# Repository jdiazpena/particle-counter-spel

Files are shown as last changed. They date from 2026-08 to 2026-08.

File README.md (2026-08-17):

# SUCHAI Particle Counter

This repository collects the hardware designs, Raspberry Pi Pico firmware, and
Raspberry Pi acquisition/postprocessing software used to build and operate a
prototype particle counter.

> **Project status:** prototype and research use. The repository is not yet a
> build-ready release. The plotting pipeline has a known altitude-column
> mismatch, and reproducible build/test environments have not yet been
> recorded. Review [Known issues](docs/known-issues.md) before manufacturing
> hardware or processing measurements.

## System overview

```text
S1223-01 photodiode
    -> analog front end
    -> four thresholds per detector (A and B)
    -> Raspberry Pi Pico pulse counters
    -> I2C
    -> Raspberry Pi Zero 2 acquisition
    -> CSV measurements
    -> TLE orbit propagation
    -> geographic and magnetic plots
```

The comparator board produces eight digital channels. `A1` through `A4` are
the four cumulative threshold outputs for detector A; `B1` through `B4` are
the corresponding outputs for detector B. The Pico counts their rising edges
and exposes eight cumulative 32-bit counters to the Raspberry Pi over I2C.

## Repository layout

```text
hardware/
  analog-front-end/             Photodiode amplifier/interstage KiCad project
  comparator-pico-interface/    Comparator, DAC, power, and Pico KiCad project
firmware/
  pico-particle-counter/        RP2040/Arduino pulse-counter firmware
software/
  raspberry-pi/                 Acquisition, orbit processing, and plotting
docs/
  hardware.md                   Boards, connectors, and signal mapping
  firmware.md                   Pico behavior, pin mapping, and I2C protocol
  raspberry-pi-software.md      Acquisition and postprocessing programs
  data-format.md                Measurement columns and derived products
  known-issues.md               Software, reproducibility, and portability limits
```

## Documentation

- [Hardware and wiring](docs/hardware.md)
- [Pico firmware](docs/firmware.md)
- [Raspberry Pi software](docs/raspberry-pi-software.md)
- [Data format](docs/data-format.md)
- [Known issues](docs/known-issues.md)

## Typical workflow

1. Review the schematics, run KiCad ERC/DRC, and assemble and verify the analog
   front end and comparator/interface boards.
2. Flash the Pico with
   [`pico_particle_counter.ino`](firmware/pico-particle-counter/pico_particle_counter.ino).
3. Connect the Pico and MCP4728 to the Raspberry Pi I2C bus.
4. Set the desired threshold voltages in
   [`MCPleves.txt`](software/raspberry-pi/MCPleves.txt).
5. Record detector A, detector B, or both using the corresponding acquisition
   script in [`software/raspberry-pi`](software/raspberry-pi).
6. Add suitable TLE files and run the orbit-cache postprocessor.
7. After addressing the documented `alt_km`/`alt` issue, generate geographic
   and magnetic-coordinate plots.

Detailed commands, paths, dependencies, and output descriptions are in the
linked documents. There is currently no published voltage-to-particle-energy
calibration, so threshold-difference products must not be described as
calibrated energy bins.

## Contributing changes

Keep hardware, firmware, and software revisions traceable. When changing a
board, record whether the schematic or PCB was the starting authority, update
both, run KiCad ERC/DRC, and document the tested physical revision. Avoid
committing KiCad lock/session/cache files or Python bytecode.

## License

No license has been added yet. Until the project owners select one, the files
should not be assumed to grant permission for redistribution or reuse.

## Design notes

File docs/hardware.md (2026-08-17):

# Hardware

The hardware is divided into an analog photodiode front end and a combined
comparator, threshold-DAC, power-control, and Pico interface board. Both are
KiCad 9 projects.

## Analog front end

Project directory: [`hardware/analog-front-end`](../hardware/analog-front-end)

The current design contains:

- one Hamamatsu S1223-01 photodiode (`D1`);
- a dual operational-amplifier stage (`IC1`);
- a REF3012 voltage reference (`U1`);
- transimpedance/filter/gain components;
- internal signals `OUTA` and `OUTB` and the connector output `OUT`;
- 5 V power and ground connections; and
- a routed two-layer, 1.6 mm PCB with 32 footprints.

The schematic is the authoritative source for component selection. The current
schematic and PCB have matching component references and displayed values. The
connector mapping below is extracted from the current
`PC_Interstage.kicad_pcb` file.

| Connector | Pin 1 | Pin 2 | Pin 3 | Pin 4 |
|---|---|---|---|---|
| J1, J7, J8, J9 | GND | 5V0 | OUT | GND |
| J6 | GND | 5V0 | OUT | GND |
| J2, J3, J4, J5 | GND | — | — | — |

Matching values do not by themselves establish electrical correctness or prove
that the PCB has been updated from the latest schematic netlist. Run ERC, update
the PCB from the schematic, and run DRC before manufacturing.

## Comparator and Pico interface

Project directory:
[`hardware/comparator-pico-interface`](../hardware/comparator-pico-interface)

The board contains:

- two LM339 quad comparators (`U5`, `U6`);
- one MCP4728 four-channel threshold DAC (`U7`);
- one Raspberry Pi Pico module (`A1`);
- separate particle-detector and camera power switching;
- AP2112K 3.3 V regulators and TPS22917 load switches;
- two analog inputs, `PC_AO1` and `PC_AO2`;
- comparator outputs `A1`–`A4` and `B1`–`B4`; and
- a routed four-layer, 1.6 mm PCB.

The current schematic and PCB have matching component references and values.
This does not constitute ERC, DRC, or physical validation.

### Functional connections

| Function | Current PCB connection |
|---|---|
| Analog input A | J2 pin 2, `PC_AO1` |
| Analog input B | J3 pin 2, `PC_AO2` |
| Comparator A outputs | J12 pins 4, 3, 2, 1 = A1, A2, A3, A4 |
| Comparator B outputs | J13 pins 4, 3, 2, 1 = B1, B2, B3, B4 |
| DAC thresholds | J9 pins 2–5 = REFA, REFB, REFC, REFD |
| Raspberry Pi I2C | `RPI_SDA`, `RPI_SCL` |
| Pico supply | `5V_PC` to Pico VSYS |

### Main 12-pin interface connector

The current `J1` PCB mapping is:

| Pin | Signal | Pin | Signal |
|---:|---|---:|---|
| 1 | GND | 7 | CAM_Switch |
| 2 | AGND | 8 | 3V3 |
| 3 | AGND | 9 | RPI_SDA |
| 4 | 5V0_IN | 10 | RPI_SCL |
| 5 | 5V0_IN | 11 | 5V0_IN |
| 6 | PD_Switch | 12 | GND |

Confirm connector orientation and pin-one markings in KiCad before wiring.

## KiCad file roles

Each project contains:

| Extension/name | Purpose | Version-control guidance |
|---|---|---|
| `.kicad_sch` | Editable electrical schematic | Track |
| `.kicad_pcb` | Board layout, footprints, routing, and outline | Track |
| `.kicad_pro` | Project and design-rule settings | Track |
| `.kicad_prl` | User-local editor/session state | Do not add new copies |
| `fp-info-cache` | Generated footprint-library cache | Do not add new copies |
| `*-backups/` | KiCad automatic working backups | Prefer tagged releases instead |
| `*.lck` | Temporary editor lock | Never track |

## External libraries and models

The designs use custom `SamacSys_Parts` and `Payload` libraries. Footprint
geometry already placed on a PCB is embedded in the board file, but editing or
re-associating some parts may require the original libraries. Several 3D model
references use absolute Windows paths under `D:\JMDP\...`; these models will
not render on another machine until the paths or libraries are configured.

Before calling a revision reproducible, collect the custom symbols,
footprints, and redistributable 3D models into project-local libraries and
record the exact KiCad version used.

## Manufacturing checklist

Before ordering boards:

1. Record the authoritative schematic and hardware revision.
2. Update the PCB from the schematic and review all resulting changes.
3. Confirm op-amp stability, photodiode polarity, feedback values, and supply
   range from component datasheets.
4. Verify every connector pinout and mating-part orientation.
5. Run KiCad ERC and DRC with KiCad 9.
6. Generate and inspect Gerbers, drill files, position files, and the BOM.
7. Record a hardware revision identifier on both the PCB and documentation.
8. Bench-test power rails and threshold voltages before installing detectors.

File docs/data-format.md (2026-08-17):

# Measurement and processed data

## Raw measurement CSV

The acquisition scripts write one row per integration window.

### Common columns

| Column | Meaning | Unit/format |
|---|---|---|
| `unix_time` | Host time when the snapshot was read | Unix seconds, UTC |
| `iso_utc` | Human-readable host timestamp | ISO 8601 UTC |
| `t_s` | Elapsed monotonic time since acquisition start | seconds |

### Counter columns

Channel names encode detector, threshold number, and configured voltage. For
example, `A1_0.450V` is detector A at threshold 1 with a 0.450 V DAC setting.

An AB file contains eight count columns in this order:

```text
A1, A2, A3, A4, B1, B2, B3, B4
```

Values are counts observed during the integration window, not the Pico's raw
cumulative totals. The acquisition program computes:

```text
window_count = (new_total - previous_total) modulo 2^32
```

Threshold channels are cumulative discriminator products. A particle counted
above threshold 4 is normally also counted by thresholds 1, 2, and 3. Adding
all thresholds would therefore count the same event multiple times.

## Normalized count products

The orbit-cache postprocessor creates consistent columns even when an input
file contains only detector A or only detector B.

| Column | Definition |
|---|---|
| `count_A_thrN` | Detector A count at threshold N; zero if absent |
| `count_B_thrN` | Detector B count at threshold N; zero if absent |
| `thrN_total` | `count_A_thrN + count_B_thrN` |
| `particles_total` | `thr1_total` |
| `counts_total` | Backward-compatible alias of `particles_total` |
| `counts_A_total` | `count_A_thr1` |
| `counts_B_total` | `count_B_thr1` |
| `counts_raw_threshold_sum` | Sum of all four threshold totals; diagnostic only |
| `thresholdN_v` | Voltage parsed from the raw channel name |

`counts_raw_threshold_sum` must not be interpreted as a number of independent
particles.

## Approximate differential bins

The postprocessor derives:

```text
bin1 = max(thr1_total - thr2_total, 0)
bin2 = max(thr2_total - thr3_total, 0)
bin3 = max(thr3_total - thr4_total, 0)
bin4 = max(thr4_total, 0)
```

These are threshold intervals. They are not calibrated particle-energy bands
unless a detector-response and voltage-to-energy calibration is supplied.

## Provenance columns

| Column | Meaning |
|---|---|
| `detector_mode` | `A`, `B`, `AB`, or `UNKNOWN` |
| `source_file` | Original acquisition CSV path |
| `unix_time_key` | Unix timestamp normalized to six decimal places for joining |

The original raw channel columns are retained for debugging.

## Orbit columns

| Column | Meaning | Unit |
|---|---|---|
| `lat` | Geodetic latitude | degrees |
| `lon` | Geodetic longitude | degrees |
| `alt_km` | Geodetic altitude | kilometres |
| `jd` | Observation time | Julian date |
| `tle_epoch` | Epoch text from the selected TLE | TLE format |
| `tle_epoch_jd` | Selected TLE epoch | Julian date |
| `tle_file` | Source catalog path | text |
| `tle_hash` | SHA-1 identifier of the selected TLE pair | hexadecimal |
| `sgp4_error` | SGP4 status code | integer |
| `sgp4_error_text` | Description when propagation fails | text |

The plot helper currently expects `alt` rather than `alt_km`; this is a known
pipeline incompatibility, not a second documented altitude field.

## Plot-ready magnetic columns

The plotting helper is intended to add:

| Column | Meaning |
|---|---|
| `times` | Parsed UTC timestamp |
| `mlat` | AACGM magnetic latitude |
| `mlon` | AACGM magnetic longitude |
| `mlt` | Magnetic local time |
| `foot_lat`, `foot_lon` | Geographic coordinates of the magnetic footpoint |
| `period` | `1` for 06:00–18:00 MLT, `0` otherwise |

AACGM conversion can be undefined for some positions, especially near the
magnetic equator. Those rows are retained with missing magnetic coordinates.

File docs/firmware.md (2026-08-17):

# Raspberry Pi Pico firmware

Firmware directory:
[`firmware/pico-particle-counter`](../firmware/pico-particle-counter)

The Arduino sketch uses the RP2040 PIO blocks to count pulses on eight inputs.
Four state machines on PIO0 count detector A, and four on PIO1 count detector
B. Interrupt handlers increment one 32-bit software counter per channel.

## Pin mapping

| Counter index | Channel | Pico GPIO | PIO/state machine |
|---:|---|---:|---|
| 0 | A1 | GP22 | PIO0 SM0 |
| 1 | A2 | GP21 | PIO0 SM1 |
| 2 | A3 | GP20 | PIO0 SM2 |
| 3 | A4 | GP19 | PIO0 SM3 |
| 4 | B1 | GP6 | PIO1 SM0 |
| 5 | B2 | GP8 | PIO1 SM1 |
| 6 | B3 | GP10 | PIO1 SM2 |
| 7 | B4 | GP12 | PIO1 SM3 |
| — | I2C SDA | GP4 | `Wire` slave interface |
| — | I2C SCL | GP5 | `Wire` slave interface |

The firmware disables internal pulls on all pulse inputs. The external circuit
must therefore provide valid logic levels and must not leave inputs floating.

## Counted event

Each PIO state machine performs this sequence:

```text
wait until input is low
wait until input is high
raise an interrupt and wait until it is cleared
repeat
```

One low-to-high transition is counted. A signal must return low before a later
pulse can be counted.

## I2C protocol

The Pico acts as an I2C slave:

| Property | Value |
|---|---|
| Address | `0x17` |
| SDA | GP4 |
| SCL | GP5 |
| Read length | 32 bytes |
| Payload | eight little-endian unsigned 32-bit totals |
| Channel order | A1, A2, A3, A4, B1, B2, B3, B4 |

The Raspberry Pi acquisition programs subtract successive snapshots using
modulo-2^32 arithmetic, so a single counter rollover is handled correctly.
The protocol has no command byte, version field, checksum, reset command, or
timestamp; the host timestamps each received snapshot.

## Source files

- [`pico_particle_counter.ino`](../firmware/pico-particle-counter/pico_particle_counter.ino)
  is the active Arduino sketch. It embeds the three PIO instructions directly.
- [`pulse_counter.pio`](../firmware/pico-particle-counter/pulse_counter.pio)
  is the readable PIO source representation.
- [`data/pulse_counter.pio`](../firmware/pico-particle-counter/data/pulse_counter.pio)
  is currently an identical duplicate. The sketch does not import either PIO
  file.

## Building and flashing

The repository does not yet pin an Arduino RP2040 core or toolchain version.
Until a tested version is recorded, use an Arduino environment that provides:

- `Arduino.h` and `Wire.h` for an RP2040/Pico target; and
- the Raspberry Pi Pico SDK hardware headers used by the sketch, including
  PIO, IRQ, GPIO, synchronization, and PIO instruction helpers.

Select the exact Raspberry Pi Pico target, compile the sketch, upload it over
USB, and confirm that the built-in LED produces a short flash approximately
once per second. Then verify I2C address `0x17` from the Raspberry Pi before
connecting live comparator outputs.

Record the tested board package, version, compiler, upload command, and Pico
model here when a reproducible firmware build is established.

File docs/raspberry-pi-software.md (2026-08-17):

# Raspberry Pi software

Software directory: [`software/raspberry-pi`](../software/raspberry-pi)

The software has three stages: acquire counter snapshots, attach orbital
position to each timestamp, and produce geographic/magnetic plots.

## Platform assumptions

The acquisition programs assume:

- a Raspberry Pi with I2C bus 1 enabled;
- Pico I2C slave address `0x17`;
- MCP4728 DAC address `0x60` on the same bus;
- permission to access `/dev/i2c-1`; and
- writable `~/Documents/PD` and `~/Documents/PD_post` directories.

The code imports the following non-standard Python packages:

| Purpose | Packages/modules |
|---|---|
| I2C acquisition | `smbus2`, Adafruit Blinka (`board`), `adafruit_mcp4728` |
| Tables/numerics | `numpy`, `pandas` |
| Orbit propagation | `sgp4`, `astropy` |
| Mapping | `matplotlib`, `geopandas`, `shapely`, `cartopy`, `aacgmv2` |

No supported OS image, Python version, or dependency lock file is currently
provided. Install these in a virtual environment appropriate to the selected
Raspberry Pi OS, then record the tested versions before deployment.

## Threshold configuration

[`MCPleves.txt`](../software/raspberry-pi/MCPleves.txt) contains exactly four
threshold voltages, one per line. The current values are:

```text
0.45
1.0
1.55
2.1
```

The A and B acquisition scripts use this file and apply the same four DAC
thresholds to both detectors. Values must remain between 0 and 4.096 V.

`read_particle_counter.py` is an older diagnostic exception: it uses hardcoded
0.5, 1.5, 2.5, and 3.5 V thresholds instead of the file.

## Acquisition programs

Run commands from `software/raspberry-pi` so local configuration and helper
imports are easy to find.

### Both detectors

```bash
python3 read_pd_AB.py TOTAL_TIME_S INTEGRATION_TIME_S
```

For example, the following requests ten minutes of data in one-second
integration windows:

```bash
python3 read_pd_AB.py 600 1
```

It writes all eight channel deltas to a uniquely named
`~/Documents/PD/PD_AB_*.csv` file. Each row is flushed and synchronized to
storage.

### Detector A only

```bash
python3 read_pd_A.py TOTAL_TIME_S INTEGRATION_TIME_S
```

This saves only A1–A4 as `PD_A_only_*.csv`.

### Detector B only

```bash
python3 read_pd_B.py TOTAL_TIME_S INTEGRATION_TIME_S
```

This saves only B1–B4 as `PD_B_only_*.csv`.

### Live diagnostic

```bash
python3 read_particle_counter.py
```

This continuously prints cumulative totals and one-second deltas. It does not
write CSV data and uses its own hardcoded DAC thresholds. Stop it with
`Ctrl+C`.

## Orbit-position processing

[`pd_build_orbit_cache.py`](../software/raspberry-pi/pd_build_orbit_cache.py)
uses hardcoded directories:

| Path | Purpose |
|---|---|
| `~/Documents/PD` | Input `PD*.csv` measurement files |
| `~/TLE` | Input two-line element catalog files |
| `~/TLE/finals2000A.all` | Optional offline Earth-orientation data |
| `~/Documents/PD_post` | Cache, joined output, and runtime report |

Run:

```bash
python3 pd_build_orbit_cache.py
```

The program accepts TLE files containing either two-line pairs or a satellite
name followed by a two-line pair. For each measurement timestamp it selects
the nearest TLE epoch, propagates with SGP4, transforms TEME coordinates to an
Earth-fixed position, and stores latitude, longitude, and altitude.

The cache avoids repeating propagation unless a timestamp is new, its position
is missing, or an updated TLE catalog changes the nearest TLE.

Expected outputs are:

- `pd_orbit_cache.csv`;
- `pd_measurements_with_position.csv`; and
- `pd_orbit_cache_runtime.txt`.

## Plotting

[`plot_pd_particles.py`](../software/raspberry-pi/plot_pd_particles.py) expects
`~/Documents/PD_post/pd_measurements_with_position.csv`, builds an AACGM
magnetic-coordinate cache, and writes PNG figures under
`~/Documents/PD_post/figures_PD`.

Intended command:

```bash
python3 plot_pd_particles.py
```

The current producer writes `alt_km`, while the plotting helper expects `alt`.
Consequently this step is known to fail without a separately authorized code
fix or a manually adapted input table. See [Known issues](known-issues.md).

The plots include geographic coordinates, AACGM magnetic coordinates,
magnetic footpoints, day/night magnetic-local-time subsets, cumulative
threshold products, and approximate threshold-difference bins.

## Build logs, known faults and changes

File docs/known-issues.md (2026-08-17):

# Known issues and release blockers

This document records problems observed in the current repository. It does not
claim that the electrical design or scientific method has been fully reviewed.

## Plotting altitude mismatch

`pd_build_orbit_cache.py` produces `alt_km`, but `Help_Functions_PD.py`
requires `alt` and attempts to access `row.alt`. The intended joined output
therefore does not satisfy the plotting helper's schema.

This requires a code decision: either standardize on `alt_km` throughout or
rename it to `alt` while clearly preserving kilometre units. Code changes are
outside the documentation/reorganization change represented here.

## Missing reproducible environments

- No Python dependency or lock file is present.
- No supported Raspberry Pi OS/Python versions are recorded.
- No Arduino RP2040 core/toolchain version is recorded.
- No automated tests or hardware-in-the-loop checks are present.
- No CI workflow validates Python syntax or documentation links.

## KiCad portability

- Custom `SamacSys_Parts` and `Payload` libraries are not included as
  project-local libraries.
- Several 3D models refer to absolute Windows paths.
- The repository already contains tracked `.kicad_prl`, `fp-info-cache`, lock,
  and automatic-backup files. These are local/generated artifacts and may
  create noisy changes or disclose workstation-specific state.
- KiCad ERC and DRC reports are not included.

## Naming and stale references

- `MCPleves.txt` likely means `MCP_levels.txt`. It cannot be renamed without
  changing three acquisition scripts that reference it.
- Comments mention `pd_build_orbit_cache_v2.py`, which is not in the repository.
- The A-only and B-only usage messages mention filenames ending in `_only.py`,
  but the committed scripts are `read_pd_A.py` and `read_pd_B.py`.
- Two identical `pulse_counter.pio` files exist, and the Arduino sketch embeds
  its PIO instructions rather than importing either one.

## Threshold inconsistency

The primary acquisition scripts load 0.45, 1.0, 1.55, and 2.1 V from
`MCPleves.txt`. The live diagnostic `read_particle_counter.py` instead programs
0.5, 1.5, 2.5, and 3.5 V. Measurements must record which program and thresholds
were used.

## Missing project information

The repository still needs:

- an approved hardware revision and validation status;
- a BOM with manufacturer part numbers and substitutions;
- assembly photographs and connector-orientation diagrams;
- a detector calibration procedure and calibration data;
- representative raw and processed example data;
- expected plots for a known dataset;
- operating limits and electrical safety notes;
- contributor/citation information; and
- an explicit software/hardware/documentation license.

## Recommended release gate

Before labeling a version build-ready:

1. update each PCB from its authoritative schematic;
2. run and archive ERC/DRC results;
3. build and bench-test both boards;
4. pin and test the Pico and Raspberry Pi environments;
5. resolve the altitude schema mismatch;
6. run a complete acquisition-to-plot test with sample data;
7. add BOM, calibration, and expected results; and
8. tag the exact tested hardware, firmware, and software revision together.

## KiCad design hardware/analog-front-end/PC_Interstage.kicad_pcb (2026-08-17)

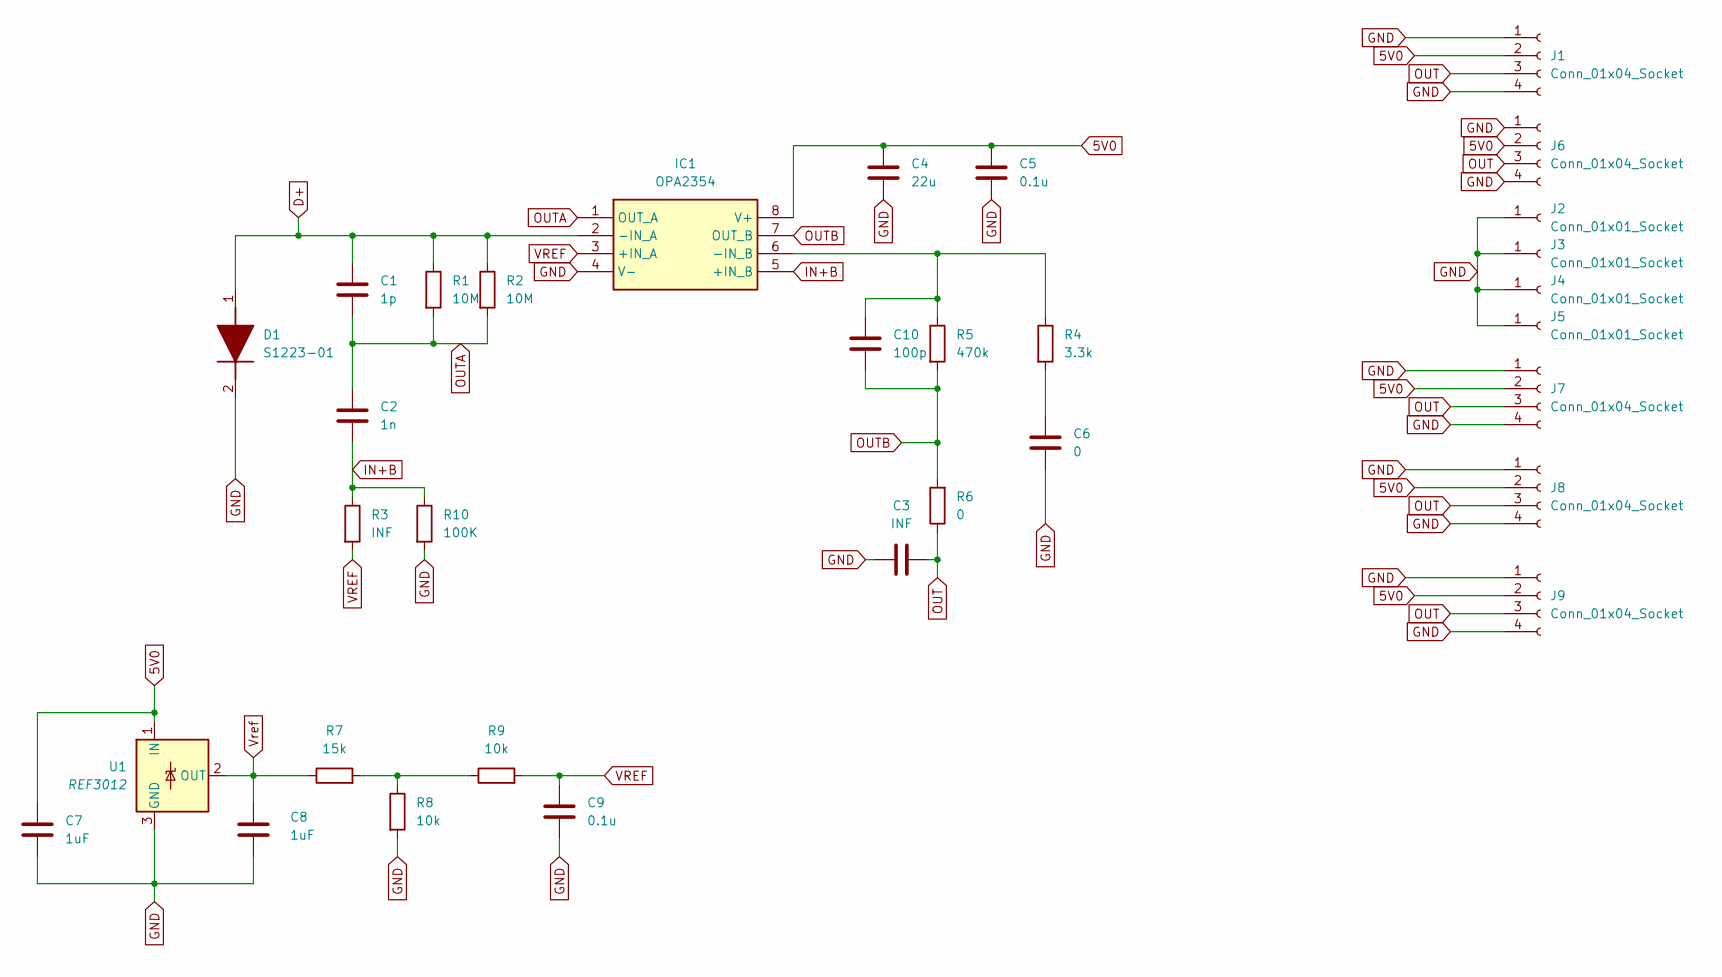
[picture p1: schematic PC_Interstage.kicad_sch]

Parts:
C1: 1p; C_0805_2012Metric
C2: 1n; C_0805_2012Metric
C3: INF; C_0805_2012Metric
C4: 22u; C_0805_2012Metric
C5, C9: 0.1u; C_0805_2012Metric
C6: 0; C_0805_2012Metric
C7, C8: 1uF; C_0805_2012Metric
C10: 100p; C_0805_2012Metric
D1: S1223-01; Manufacturer_Part_Number S1223-01
IC1: OPA2354; SOIC127P600X175-8N; Manufacturer_Part_Number OPA1678IDR; Mouser Part Number 595-OPA1678IDR
J1, J7, J8, J9: Conn_01x04_Socket; Molex_Pico-Lock_504050-0491_1x04-1MP_P1.50mm_Horizontal
J2, J3, J4, J5: Conn_01x01_Socket; PinHeader_1x01_P2.54mm_Vertical
J6: Conn_01x04_Socket; PinHeader_1x04_P2.54mm_Vertical
R1: 10M; R_0805_2012Metric
R2: 10M; R_1206_3216Metric_Pad1.30x1.75mm_HandSolder
R3: INF; R_0805_2012Metric
R4: 3.3k; R_0805_2012Metric
R5: 470k; R_0805_2012Metric
R6: 0; R_0805_2012Metric
R7: 15k; R_0805_2012Metric
R8, R9: 10k; R_0805_2012Metric
R10: 100K; R_0805_2012Metric
U1: REF3012; SOT-23

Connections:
5V0: C4.1, C5.1, C7.1, IC1.8 (V+), J1.2, J6.2, J7.2, J8.2, J9.2, U1.1 (IN)
D+: C1.1, D1.1 (A), IC1.2 (-IN_A), R1.1, R2.1
GND: C3.2, C4.2, C5.2, C6.2, C7.2, C8.2, C9.2, D1.2 (K), IC1.4 (V-), J1.1, J1.4, J2.1, J3.1, J4.1, J5.1, J6.1, J6.4, J7.1, J7.4, J8.1, J8.4, J9.1, J9.4, R8.2, R10.2, U1.3 (GND)
IN+B: C2.2, IC1.5 (+IN_B), R3.1, R10.1
unnamed: C6.1, R4.2
unnamed: C10.1, IC1.6 (-IN_B), R4.1, R5.1
unnamed: R7.2, R8.1, R9.1
OUT: C3.1, J1.3, J6.3, J7.3, J8.3, J9.3, R6.1
OUTA: C1.2, C2.1, IC1.1 (OUT_A), R1.2, R2.2
OUTB: C10.2, IC1.7 (OUT_B), R5.2, R6.2
VREF: C9.1, IC1.3 (+IN_A), R3.2, R9.2
Vref: C8.1, R7.1, U1.2 (OUT)

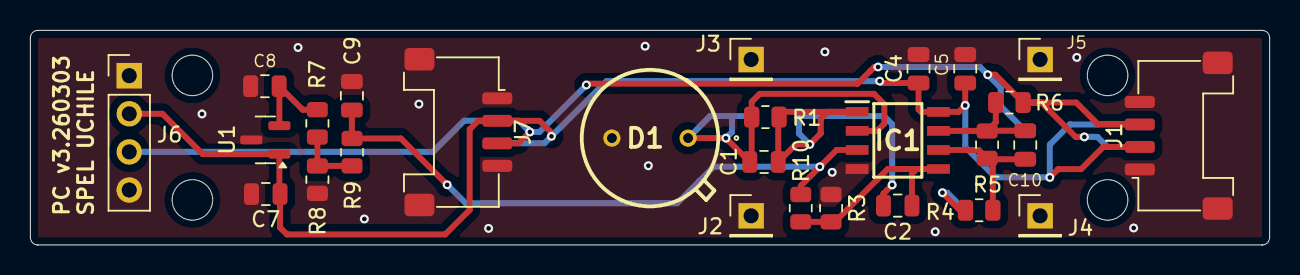
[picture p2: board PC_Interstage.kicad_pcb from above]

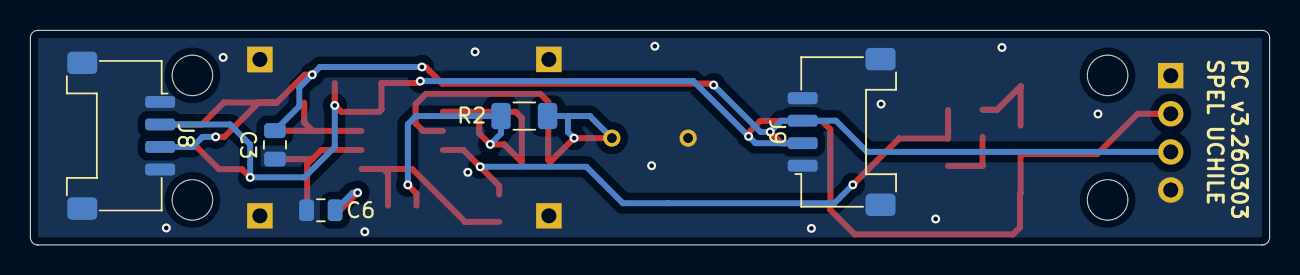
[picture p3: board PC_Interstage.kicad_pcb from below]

Board: 2 copper layers, 82.6 x 14.3 mm, 32 parts (5 on the bottom side), 12 nets.

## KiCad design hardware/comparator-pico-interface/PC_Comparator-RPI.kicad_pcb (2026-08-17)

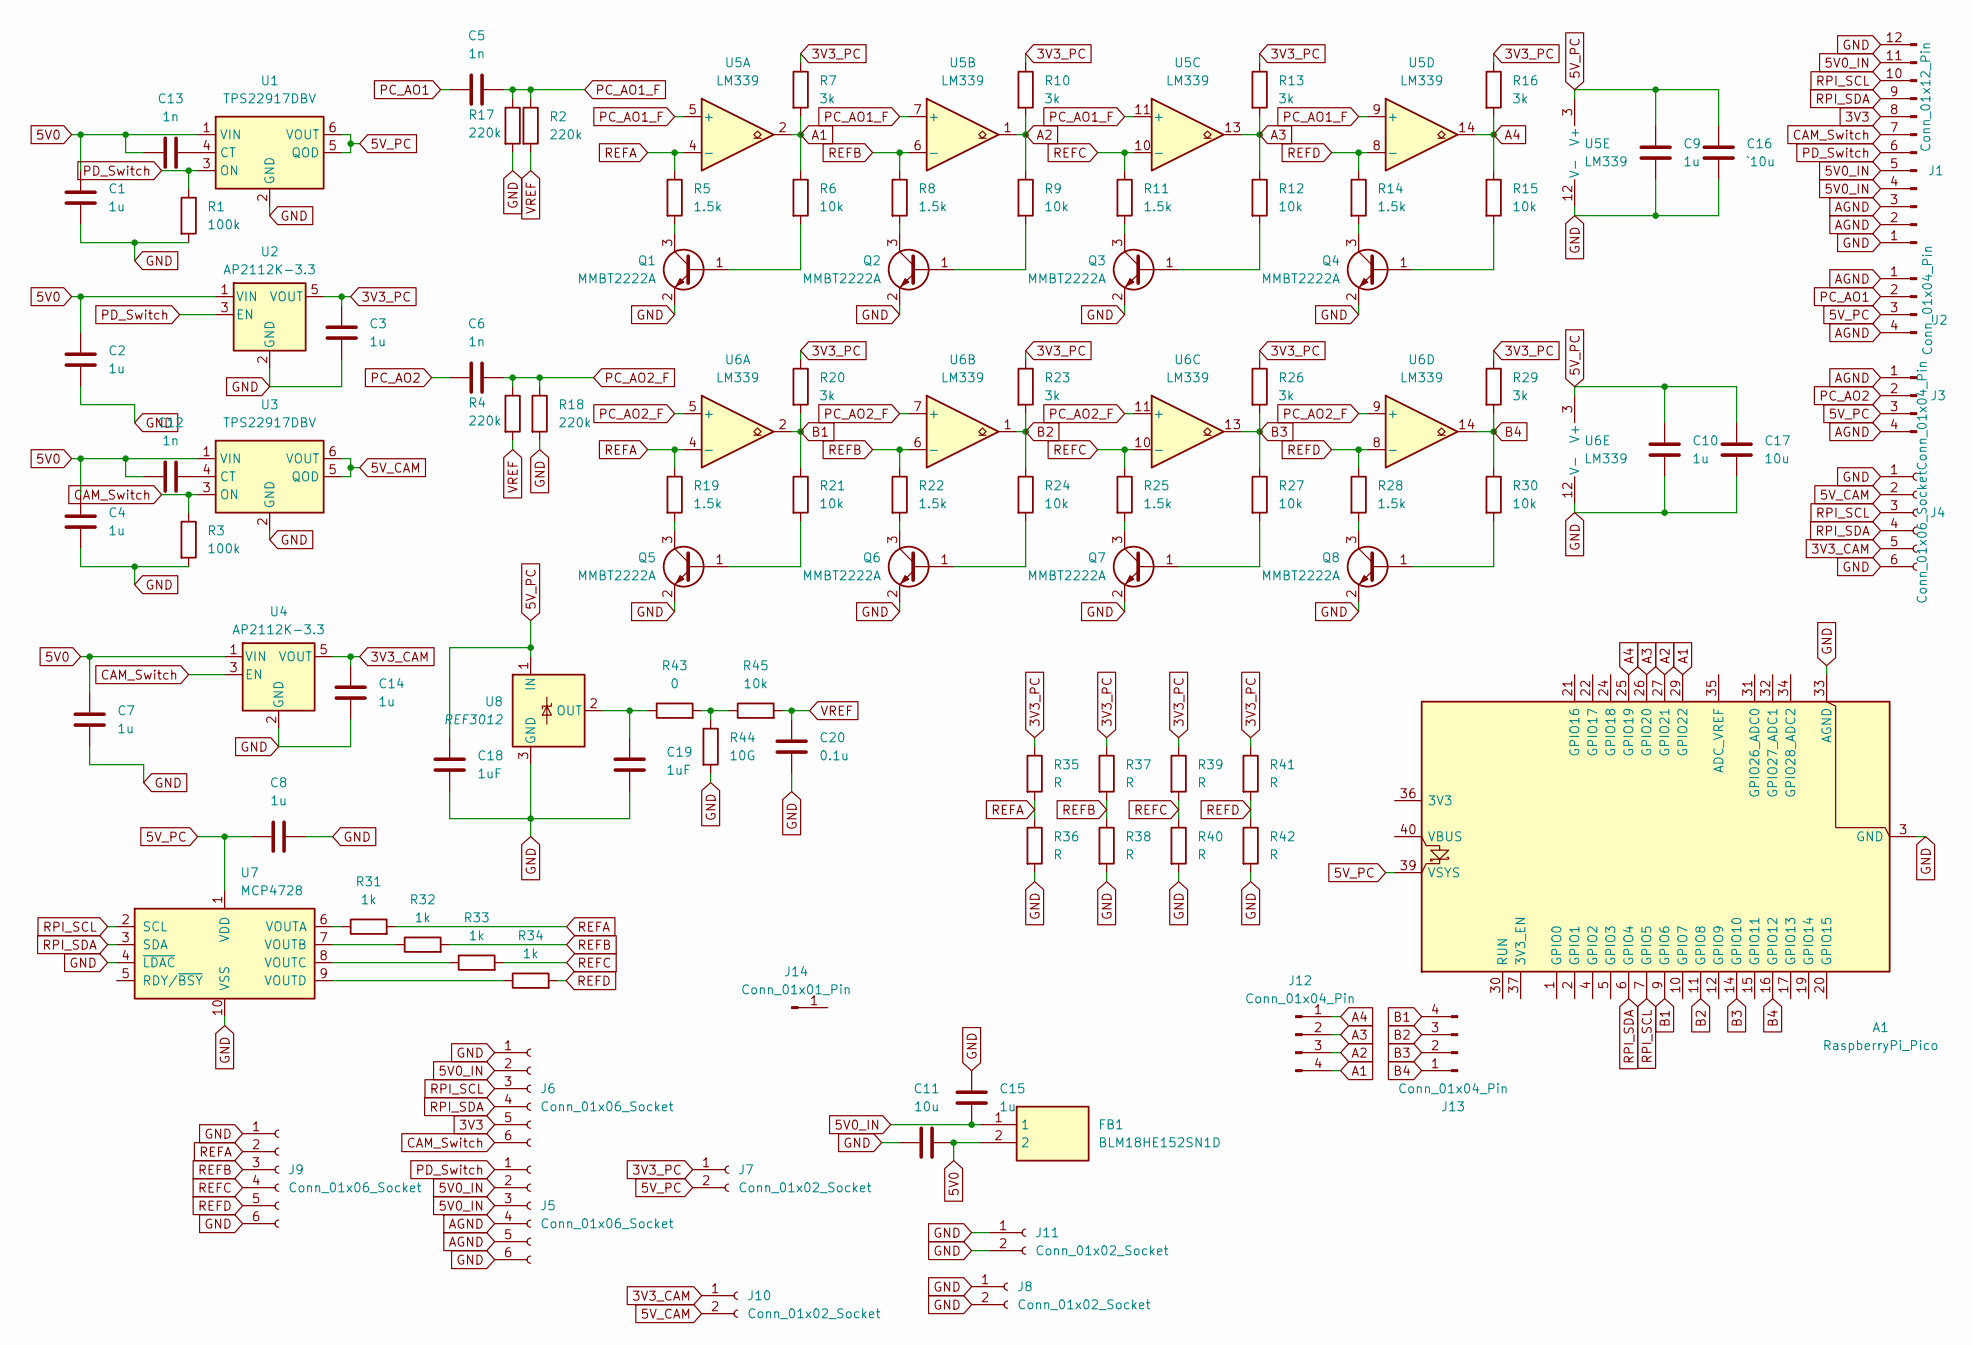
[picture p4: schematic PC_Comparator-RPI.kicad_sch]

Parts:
A1: RaspberryPi_Pico; RaspberryPi_Pico_Common_Unspecified
C1, C2, C3, C4, C7, C8, C9, C10, C14, C15: 1u; C_0805_2012Metric_Pad1.18x1.45mm_HandSolder
C5, C6, C12, C13: 1n; C_0805_2012Metric_Pad1.18x1.45mm_HandSolder
C11, C17: 10u; C_0805_2012Metric_Pad1.18x1.45mm_HandSolder
C16: `10u; C_0805_2012Metric_Pad1.18x1.45mm_HandSolder
C18, C19: 1uF; C_0805_2012Metric
C20: 0.1u; C_0805_2012Metric
FB1: BLM18HE152SN1D; BLM18SP221SN1B; Manufacturer_Part_Number BLM18HE152SN1D; Mouser Part Number 81-BLM18HE152SN1D
J1: Conn_01x12_Pin; 5040501291
J2, J3: Conn_01x04_Pin; Molex_Pico-Lock_504050-0491_1x04-1MP_P1.50mm_Horizontal
J4: Conn_01x06_Socket; Molex_Pico-Lock_504050-0691_1x06-1MP_P1.50mm_Horizontal
J5, J6, J9: Conn_01x06_Socket; PinSocket_1x06_P2.54mm_Vertical
J7, J8, J10, J11: Conn_01x02_Socket; PinHeader_1x02_P2.54mm_Vertical
J12, J13: Conn_01x04_Pin; PinHeader_1x04_P2.54mm_Vertical
J14: Conn_01x01_Pin; PinSocket_1x01_P2.54mm_Vertical
Q1, Q2, Q3, Q4, Q5, Q6, Q7, Q8: MMBT2222A; SOT-23
R1, R3: 100k; R_0805_2012Metric_Pad1.20x1.40mm_HandSolder
R2, R4, R17, R18: 220k; R_0805_2012Metric_Pad1.20x1.40mm_HandSolder
R5, R8, R11, R14, R19, R22, R25, R28: 1.5k; R_0805_2012Metric_Pad1.20x1.40mm_HandSolder
R6, R9, R12, R15, R21, R24, R27, R30: 10k; R_0805_2012Metric_Pad1.20x1.40mm_HandSolder
R7, R10, R13, R16, R20, R23, R26, R29: 3k; R_0805_2012Metric_Pad1.20x1.40mm_HandSolder
R31, R32, R33, R34: 1k; R_0805_2012Metric_Pad1.20x1.40mm_HandSolder
R35, R36, R37, R38, R39, R40, R41, R42: R; R_0805_2012Metric_Pad1.20x1.40mm_HandSolder
R43: 0; R_0805_2012Metric
R44: 10G; R_0805_2012Metric
R45: 10k; R_0805_2012Metric
U1, U3: TPS22917DBV; SOT-23-6
U2, U4: AP2112K-3.3; SOT-23-5
U5, U6: LM339; SO-14_5.3x10.2mm_P1.27mm
U7: MCP4728; MSOP-10_3x3mm_P0.5mm
U8: REF3012; SOT-23

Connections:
3V3: J1.8, J6.5
3V3_CAM: C14.1, J4.5, J10.1, U4.5 (VOUT)
3V3_PC: C3.1, J7.1, R7.1, R10.1, R13.1, R16.1, R20.1, R23.1, R26.1, R29.1, R35.1, R37.1, R39.1, R41.1, U2.5 (VOUT)
5V0: C1.1, C2.1, C4.1, C7.1, C11.1, C12.1, C13.1, FB1.2, U1.1 (VIN), U2.1 (VIN), U3.1 (VIN), U4.1 (VIN)
5V0_IN: C15.2, FB1.1, J1.4, J1.5, J1.11, J5.2, J5.3, J6.2
5V_CAM: J4.2, J10.2, U3.5 (QOD), U3.6 (VOUT)
5V_PC: A1.39 (VSYS), C8.2, C9.1, C10.1, C16.1, C17.1, C18.1, J2.3, J3.3, J7.2, U1.5 (QOD), U1.6 (VOUT), U5.3 (V+), U6.3 (V+), U7.1 (VDD), U8.1 (IN)
A1: A1.29 (GPIO22), J12.4, R6.1, R7.2, U5.2
A2: A1.27 (GPIO21), J12.3, R9.1, R10.2, U5.1
A3: A1.26 (GPIO20), J12.2, R12.1, R13.2, U5.13
A4: A1.25 (GPIO19), J12.1, R15.1, R16.2, U5.14
AGND: J1.2, J1.3, J2.1, J2.4, J3.1, J3.4, J5.4, J5.5
B1: A1.9 (GPIO6), J13.4, R20.2, R21.1, U6.2
B2: A1.11 (GPIO8), J13.3, R23.2, R24.1, U6.1
B3: A1.14 (GPIO10), J13.2, R26.2, R27.1, U6.13
B4: A1.16 (GPIO12), J13.1, R29.2, R30.1, U6.14
CAM_Switch: J1.7, J6.6, R3.1, U3.3 (ON), U4.3 (EN)
GND: A1.3 (GND), A1.8 (GND), A1.13 (GND), A1.18 (GND), A1.23 (GND), A1.28 (GND), A1.33 (AGND), A1.38 (GND), C1.2, C2.2, C3.2, C4.2, C7.2, C8.1, C9.2, C10.2, C11.2, C14.2, C15.1, C16.2, C17.2, C18.2, C19.2, C20.2, J1.1, J1.12, J4.1, J4.6, J5.6, J6.1, J8.1, J8.2, J9.1, J9.6, J11.1, J11.2, Q1.2 (E), Q2.2 (E), Q3.2 (E), Q4.2 (E), Q5.2 (E), Q6.2 (E), Q7.2 (E), Q8.2 (E), R1.2, R3.2, R17.2, R18.2, R36.2, R38.2, R40.2, R42.2, R44.2, U1.2 (GND), U2.2 (GND), U3.2 (GND), U4.2 (GND), U5.12 (V-), U6.12 (V-), U7.4 (~LDAC), U7.10 (VSS), U8.3 (GND)
unnamed: Q1.1 (B), R6.2
unnamed: Q1.3 (C), R5.2
unnamed: Q2.1 (B), R9.2
unnamed: Q2.3 (C), R8.2
unnamed: Q3.1 (B), R12.2
unnamed: Q3.3 (C), R11.2
unnamed: Q4.1 (B), R15.2
unnamed: Q4.3 (C), R14.2
unnamed: Q5.1 (B), R21.2
unnamed: Q5.3 (C), R19.2
unnamed: Q6.1 (B), R24.2
unnamed: Q6.3 (C), R22.2
unnamed: Q7.1 (B), R27.2
unnamed: Q7.3 (C), R25.2
unnamed: Q8.1 (B), R30.2
unnamed: Q8.3 (C), R28.2
unnamed: R43.2, R44.1, R45.1
unnamed: C13.2, U1.4 (CT)
unnamed: C12.2, U3.4 (CT)
unnamed: R31.1, U7.6 (VOUTA)
unnamed: R32.1, U7.7 (VOUTB)
unnamed: R33.1, U7.8 (VOUTC)
unnamed: R34.1, U7.9 (VOUTD)
unnamed: C19.1, R43.1, U8.2 (OUT)
PC_AO1: C5.2, J2.2
PC_AO1_F: C5.1, R2.1, R17.1, U5.5 (+), U5.7 (+), U5.9 (+), U5.11 (+)
PC_AO2: C6.2, J3.2
PC_AO2_F: C6.1, R4.1, R18.1, U6.5 (+), U6.7 (+), U6.9 (+), U6.11 (+)
PD_Switch: J1.6, J5.1, R1.1, U1.3 (ON), U2.3 (EN)
REFA: J9.2, R5.1, R19.1, R31.2, R35.2, R36.1, U5.4 (-), U6.4 (-)
REFB: J9.3, R8.1, R22.1, R32.2, R37.2, R38.1, U5.6 (-), U6.6 (-)
REFC: J9.4, R11.1, R25.1, R33.2, R39.2, R40.1, U5.10 (-), U6.10 (-)
REFD: J9.5, R14.1, R28.1, R34.2, R41.2, R42.1, U5.8 (-), U6.8 (-)
RPI_SCL: A1.7 (GPIO5), J1.10, J4.3, J6.3, U7.2 (SCL)
RPI_SDA: A1.6 (GPIO4), J1.9, J4.4, J6.4, U7.3 (SDA)
VREF: C20.1, R2.2, R4.2, R45.2

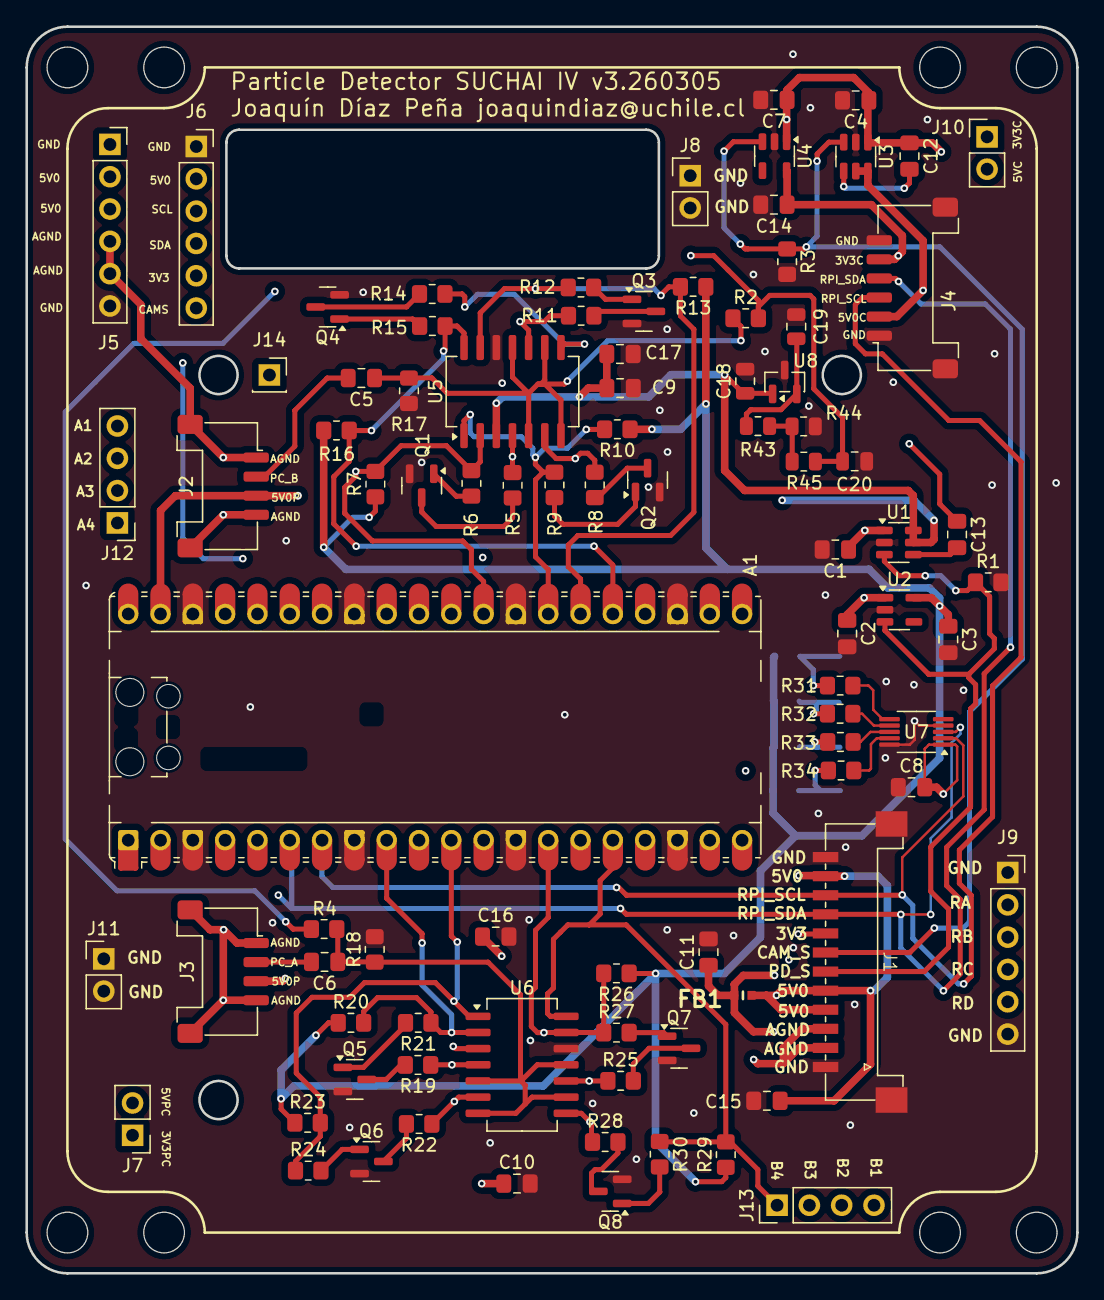
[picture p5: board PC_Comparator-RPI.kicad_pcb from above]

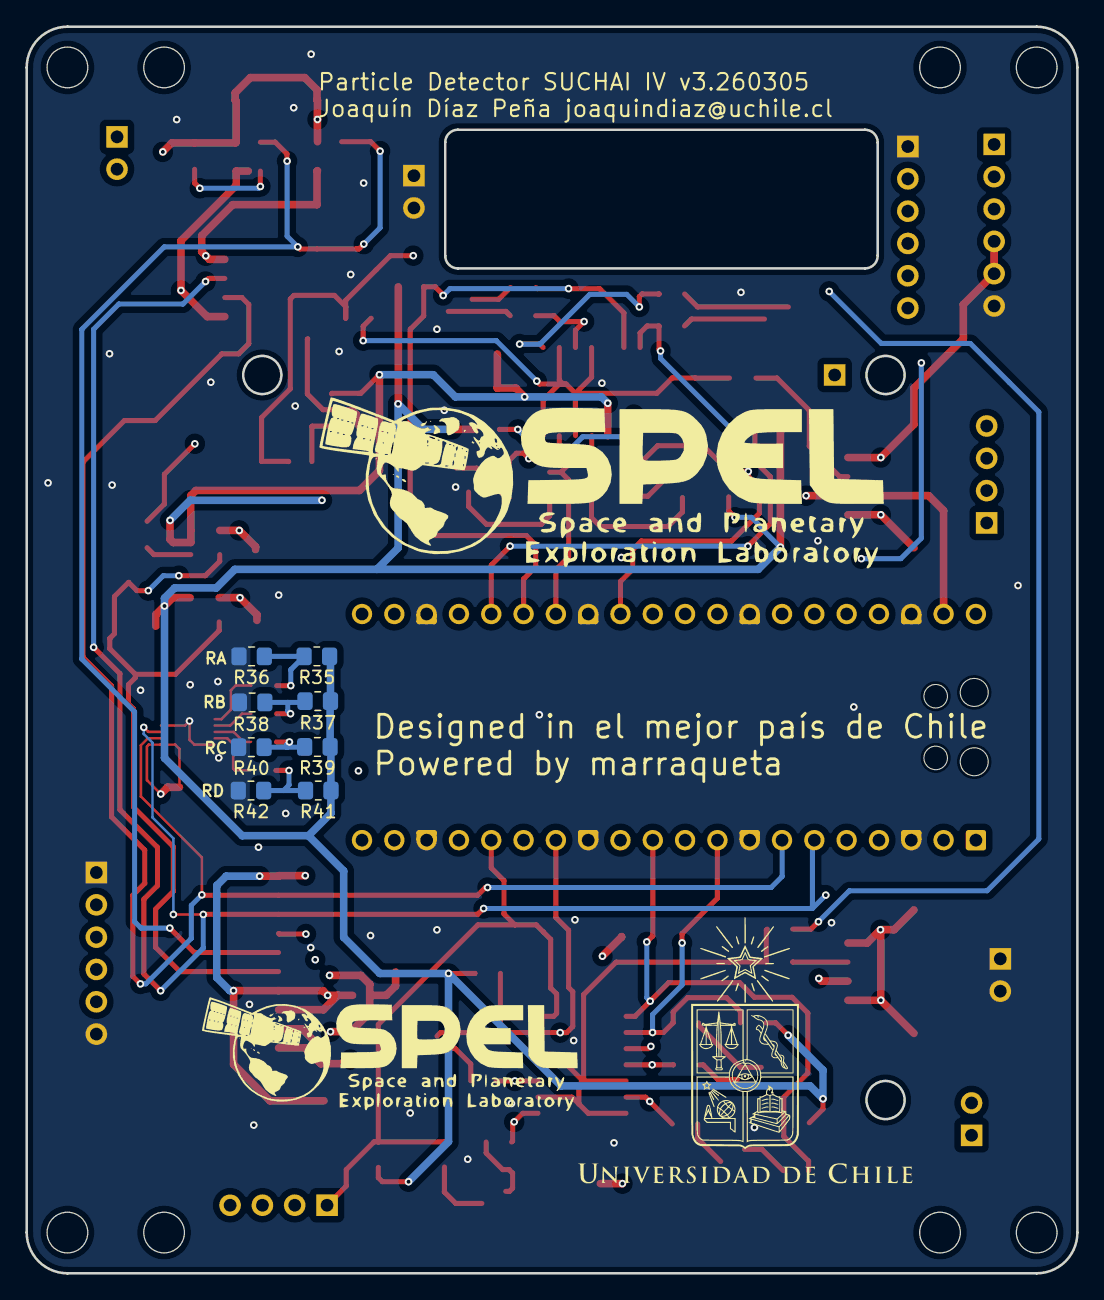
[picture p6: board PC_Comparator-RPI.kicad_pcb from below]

Board: 4 copper layers, 82.6 x 98.0 mm, 97 parts (8 on the bottom side), 54 nets.

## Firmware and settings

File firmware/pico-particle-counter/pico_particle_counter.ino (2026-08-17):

#include <Arduino.h>
#include <Wire.h>

#include "hardware/pio.h"
#include "hardware/irq.h"
#include "hardware/gpio.h"
#include "hardware/sync.h"
#include "hardware/pio_instructions.h"

#define I2C_ADDR 0x17

#define I2C_SDA 4
#define I2C_SCL 5

// Channel order:
// A1, A2, A3, A4, B1, B2, B3, B4
static const uint8_t CHANNEL_PINS[8] = {
  22,  // A1
  21,  // A2
  20,  // A3
  19,  // A4
   6,  // B1
   8,  // B2
  10,  // B3
  12   // B4
};

volatile uint32_t counters[8] = {0};

// PIO program, written directly as instructions.
// Equivalent to:
//
// .wrap_target
//     wait 0 pin 0
//     wait 1 pin 0
//     irq wait rel 0
// .wrap
//
static const uint16_t pulse_counter_program_instructions[] = {
  (uint16_t)pio_encode_wait_pin(false, 0),
  (uint16_t)pio_encode_wait_pin(true,  0),
  (uint16_t)pio_encode_irq_wait(true, 0)
};

static const struct pio_program pulse_counter_program = {
  .instructions = pulse_counter_program_instructions,
  .length = 3,
  .origin = -1
};

void pack_u32_le(uint8_t *buf, uint32_t value) {
  buf[0] = (value >> 0)  & 0xFF;
  buf[1] = (value >> 8)  & 0xFF;
  buf[2] = (value >> 16) & 0xFF;
  buf[3] = (value >> 24) & 0xFF;
}

void onRequest() {
  uint32_t snapshot[8];
  uint8_t buffer[32];

  uint32_t irq_state = save_and_disable_interrupts();

  for (int i = 0; i < 8; i++) {
    snapshot[i] = counters[i];
  }

  restore_interrupts(irq_state);

  for (int i = 0; i < 8; i++) {
    pack_u32_le(&buffer[4 * i], snapshot[i]);
  }

  Wire.write(buffer, 32);
}

void pio0_irq0_handler() {
  for (int sm = 0; sm < 4; sm++) {
    if (pio_interrupt_get(pio0, sm)) {
      counters[sm]++;
      pio_interrupt_clear(pio0, sm);
    }
  }
}

void pio1_irq0_handler() {
  for (int sm = 0; sm < 4; sm++) {
    if (pio_interrupt_get(pio1, sm)) {
      counters[4 + sm]++;
      pio_interrupt_clear(pio1, sm);
    }
  }
}

void setup_one_counter(PIO pio, uint sm, uint offset, uint gpio) {
  gpio_init(gpio);
  gpio_disable_pulls(gpio);

  pio_gpio_init(pio, gpio);
  pio_sm_set_consecutive_pindirs(pio, sm, gpio, 1, false);

  pio_sm_config c = pio_get_default_sm_config();

  sm_config_set_in_pins(&c, gpio);

  // Program length = 3 instructions.
  // Wrap from instruction offset+2 back to offset+0.
  sm_config_set_wrap(&c, offset + 0, offset + 2);

  pio_sm_init(pio, sm, offset, &c);
  pio_sm_set_enabled(pio, sm, true);
}

void setup_pio_counters() {
  uint offset0 = pio_add_program(pio0, &pulse_counter_program);
  uint offset1 = pio_add_program(pio1, &pulse_counter_program);

  irq_set_exclusive_handler(PIO0_IRQ_0, pio0_irq0_handler);
  irq_set_exclusive_handler(PIO1_IRQ_0, pio1_irq0_handler);

  for (int sm = 0; sm < 4; sm++) {
    pio_set_irq0_source_enabled(pio0, (pio_interrupt_source_t)(pis_interrupt0 + sm), true);
    pio_set_irq0_source_enabled(pio1, (pio_interrupt_source_t)(pis_interrupt0 + sm), true);
  }

  irq_set_enabled(PIO0_IRQ_0, true);
  irq_set_enabled(PIO1_IRQ_0, true);

  setup_one_counter(pio0, 0, offset0, CHANNEL_PINS[0]);  // A1 GPIO22
  setup_one_counter(pio0, 1, offset0, CHANNEL_PINS[1]);  // A2 GPIO21
  setup_one_counter(pio0, 2, offset0, CHANNEL_PINS[2]);  // A3 GPIO20
  setup_one_counter(pio0, 3, offset0, CHANNEL_PINS[3]);  // A4 GPIO19

  setup_one_counter(pio1, 0, offset1, CHANNEL_PINS[4]);  // B1 GPIO6
  setup_one_counter(pio1, 1, offset1, CHANNEL_PINS[5]);  // B2 GPIO8
  setup_one_counter(pio1, 2, offset1, CHANNEL_PINS[6]);  // B3 GPIO10
  setup_one_counter(pio1, 3, offset1, CHANNEL_PINS[7]);  // B4 GPIO12
}

void setup_i2c() {
  Wire.setSDA(I2C_SDA);
  Wire.setSCL(I2C_SCL);

  Wire.begin(I2C_ADDR);
  Wire.onRequest(onRequest);
}

void setup() {
  pinMode(LED_BUILTIN, OUTPUT);

  setup_pio_counters();
  setup_i2c();
}

void loop() {
  digitalWrite(LED_BUILTIN, HIGH);
  delay(100);
  digitalWrite(LED_BUILTIN, LOW);
  delay(900);
}

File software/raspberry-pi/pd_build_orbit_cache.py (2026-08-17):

#!/usr/bin/env python3
"""
Post-process particle detector CSVs and build/update an orbit position cache.

This script is meant to be run later, after read_pd_A.py, read_pd_B.py,
or read_pd_AB.py have produced CSV files.

It does three things:
  1) Reads every particle detector CSV in PD_DATA_DIR.
  2) Builds/updates a cached timestamp -> lat/lon/alt CSV using TLEs in TLE_DIR.
  3) Writes a joined particle-detector + position CSV for later plotting.

The expensive TLE propagation is only done for:
  - new measurement timestamps not already in the cache
  - cached timestamps whose nearest TLE changed because new TLEs were added
  - cached timestamps with missing lat/lon/alt
"""

from __future__ import annotations

import hashlib
import re
import time
from dataclasses import dataclass
from datetime import datetime, timezone
from pathlib import Path

import numpy as np
import pandas as pd

from sgp4.api import Satrec, WGS84, SGP4_ERRORS
from astropy.time import Time
from astropy.coordinates import TEME, ITRS, CartesianDifferential, CartesianRepresentation
from astropy import units as u
from astropy.utils import iers
from astropy.utils.iers import IERS_A


# -----------------------------
# HARDCODED PATHS
# -----------------------------

PD_DATA_DIR = Path.home() / "Documents" / "PD"
TLE_DIR = Path.home() / "TLE"
POST_DIR = Path.home() / "Documents" / "PD_post"

ORBIT_CACHE_CSV = POST_DIR / "pd_orbit_cache.csv"
JOINED_OUTPUT_CSV = POST_DIR / "pd_measurements_with_position.csv"
RUNTIME_REPORT_TXT = POST_DIR / "pd_orbit_cache_runtime.txt"

# If this is True, old cached rows are recomputed when a newer TLE catalogue
# changes which TLE is closest to that measurement timestamp.
REFINE_IF_NEAREST_TLE_CHANGED = True

# Optional high-precision EOP file. Put it here if you want the same style
# as the old TLE_functions.py workflow:
#   $HOME/TLE/finals2000A.all
EOP_FILE = TLE_DIR / "finals2000A.all"


# -----------------------------
# TIME / TLE HELPERS
# -----------------------------

def setup_iers_offline() -> None:
    """Avoid Astropy trying to download EOP files on the RPi."""
    iers.conf.auto_download = False

    if EOP_FILE.exists():
        iers.conf.iers_table = IERS_A.open(EOP_FILE)
        print(f"Using EOP file: {EOP_FILE}")
    else:
        print(f"EOP file not found: {EOP_FILE}")
        print("Continuing with Astropy's available offline IERS table.")


def jday(year: int, mon: int, day: int, hr: int, minute: int, sec: float) -> float:
    jd0 = (
        367.0 * year
        - 7.0 * (year + ((mon + 9.0) // 12.0)) * 0.25 // 1.0
        + 275.0 * mon // 9.0
        + day
        + 1721013.5
    )
    utc = ((sec / 60.0 + minute) / 60.0 + hr)
    return jd0 + utc / 24.0


def unix_to_julian(unix_time_s: np.ndarray) -> np.ndarray:
    return 2440587.5 + np.asarray(unix_time_s, dtype=float) / 86400.0


def tle_epoch_to_julian(tle_epoch: str) -> float:
    year = int(tle_epoch[:2])
    day_of_year = int(tle_epoch[2:5])
    fraction_of_day = float("0" + tle_epoch[5:])

    # This assumes 20xx, which is fine for the current SUCHAI files.
    # If you ever process 1990s TLEs, this needs the standard TLE pivot rule.
    base_date = jday(2000 + year, 1, 0, 0, 0, 0)
    return base_date + day_of_year + fraction_of_day


def sha1_text(text: str) -> str:
    return hashlib.sha1(text.encode("utf-8")).hexdigest()


@dataclass(frozen=True)
class TLEEntry:
    file: str
    line1: str
    line2: str
    epoch: str
    epoch_jd: float
    tle_hash: str


def read_tle_catalog(tle_dir: Path) -> list[TLEEntry]:
    """
    Read all TLE pairs from text files in TLE_DIR.

    Accepts either:
      line 1
      line 2

    or:
      satellite name
      line 1
      line 2
    """
    if not tle_dir.exists():
        raise FileNotFoundError(f"TLE directory does not exist: {tle_dir}")

    entries: list[TLEEntry] = []
    tle_files = sorted(
        p for p in tle_dir.rglob("*")
        if p.is_file() and p.name != EOP_FILE.name
    )

    for path in tle_files:
        with path.open("r", errors="replace") as f:
            lines = [line.strip() for line in f if line.strip()]

        i = 0
        while i < len(lines):
            if lines[i].startswith("1 ") and i + 1 < len(lines) and lines[i + 1].startswith("2 "):
                line1 = lines[i]
                line2 = lines[i + 1]
                parts = re.split(r"\s+", line1)

                if len(parts) < 4:
                    print(f"Skipping malformed TLE line in {path}: {line1}")
                    i += 1
                    continue

                epoch = parts[3]
                epoch_jd = tle_epoch_to_julian(epoch)
                tle_hash = sha1_text(line1 + "\n" + line2)

                entries.append(
                    TLEEntry(
                        file=str(path),
                        line1=line1,
                        line2=line2,
                        epoch=epoch,
                        epoch_jd=epoch_jd,
                        tle_hash=tle_hash,
                    )
                )
                i += 2
            else:
                i += 1

    if not entries:
        raise RuntimeError(f"No valid TLE pairs found in {tle_dir}")

    entries = sorted(entries, key=lambda x: x.epoch_jd)
    print(f"Loaded {len(entries)} TLE pairs from {tle_dir}")
    print(f"TLE range JD: {entries[0].epoch_jd:.6f} to {entries[-1].epoch_jd:.6f}")
    return entries


def nearest_tle_indices(jd_obs: np.ndarray, tle_jd: np.ndarray) -> np.ndarray:
    """Return the index of the nearest TLE epoch for every observation JD."""
    jd_obs = np.asarray(jd_obs, dtype=float)
    tle_jd = np.asarray(tle_jd, dtype=float)

    right = np.searchsorted(tle_jd, jd_obs, side="left")
    left = np.clip(right - 1, 0, len(tle_jd) - 1)

    d_left = np.abs(jd_obs - tle_jd[left])
    d_right = np.where(
        right < len(tle_jd),
        np.abs(jd_obs - tle_jd[np.clip(right, 0, len(tle_jd) - 1)]),
        np.inf,
    )

    return np.where(d_right < d_left, right, left)


# -----------------------------
# PARTICLE DETECTOR CSV HELPERS
# -----------------------------

def find_pd_files(pd_dir: Path) -> list[Path]:
    if not pd_dir.exists():
        raise FileNotFoundError(f"Particle detector directory does not exist: {pd_dir}")

    files = sorted(pd_dir.rglob("PD*.csv"))
    files = [p for p in files if p.is_file()]

    if not files:
        raise RuntimeError(f"No PD*.csv files found in {pd_dir}")

    return files


def channel_columns(df: pd.DataFrame, prefix: str) -> list[str]:
    """Return raw channel columns such as A1_0.500V or B4_3.500V."""
    pattern = re.compile(rf"^{prefix}[1-4]_.*V$")
    return [c for c in df.columns if pattern.match(c)]


def channel_number(col: str) -> int | None:
    """Extract the discriminator number from a column name such as A3_2.500V."""
    match = re.match(r"^[AB]([1-4])_", col)
    if not match:
        return None
    return int(match.group(1))
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

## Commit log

2026-08-17 firt commit
    [PC_Comparator-RPI.kicad_pcb, PC_Comparator-RPI.kicad_sch, PC_Interstage.kicad_pcb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]
2026-08-17 file organization and documentatio
    [PC_Comparator-RPI.kicad_pcb, PC_Comparator-RPI.kicad_sch, PC_Interstage.kicad_pcb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]
2026-08-17 fix inconsistency
    [PC_Interstage.kicad_pcb]
